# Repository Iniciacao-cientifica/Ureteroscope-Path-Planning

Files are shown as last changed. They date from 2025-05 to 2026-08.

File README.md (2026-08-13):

# Semi-automatic Ureteroscopy Planning VR

Academic prototype that converts a navigable urinary-tract mask into validated routes and an interactive Meta Quest case. The clinical workflow remains human-in-the-loop: anatomy and entry point are reviewed before route generation.

> Research/training prototype only. It is not validated for diagnosis, patient care, intra-operative navigation, or robotic control.

## Current workflow

```text
Reviewed anatomy mask + entry point
                 |
Optional stone mask -> automatic 3D components and targets
                 |
             A* routes
                 |
Safe B-Spline + route validation
                 |
manifest.json + OBJ meshes + routes.json
                 |
Unity/OpenXR -> Meta Quest
```

The original classification project is intentionally not required. A stone segmentation mask can be supplied when a validated model is available; otherwise the operator provides a target.

## Quick start

Install Python dependencies and generate the sample case:

```powershell
python -m pip install -r requirements-vr-export.txt
.\build_vr_case.cmd -MaskDir map -CaseId murillo_sample_case -SpacingMm "2,2,2"
```

This creates `cases/murillo_sample_case/`, validates it, and synchronizes it with `UnityVRPrototype/Assets/StreamingAssets/Cases/`.

With a 3D stone mask in the same geometry:

```powershell
.\build_vr_case.cmd `
  -MaskDir "data\case_001\lumen" `
  -StoneMask "data\case_001\stones.nii.gz" `
  -CaseId "case_001" `
  -Start "253,355,20" `
  -SpacingMm "0.72,0.72,1.0"
```

The stone mask is split into 3D connected components. The pipeline calculates centroid, volume, equivalent diameter, and a route for each retained component. If a centroid is outside the navigable mask, the planning target is snapped to its nearest navigable voxel and both locations remain recorded.

## Build and install on Quest

After installing Android Build Support and configuring the headset:

```powershell
.\build_vr_case.cmd -MaskDir map -CaseId murillo_sample_case -SpacingMm "2,2,2" -BuildApk
```

To build and install on an authorized USB-connected Quest:

```powershell
.\build_vr_case.cmd -MaskDir map -CaseId murillo_sample_case -SpacingMm "2,2,2" -Install
```

The APK is written to `UnityVRPrototype/Builds/UreteroscopyVR.apk`. See [Quest setup and testing](docs/QUEST_TESTING.md).

## Unity interaction

- Grip with one controller: move and rotate the model.
- Grip with both controllers: move and scale the model.
- `X`: anatomy visibility.
- `Y`: route visibility.
- `A`: start/stop route marker.
- `B`: next route/stone.
- Left thumbstick up/down: anatomy opacity.
- Left thumbstick click: reset model.
- Right thumbstick left/right: previous/next case.
- Controller ray + trigger: use the world-space menu.

Editor keyboard fallback: `O`, `P`, `F`, `N`, `C`, `R`, `+`, and `-`.

## Desktop training game

The Unity project also includes a monitor-based academic training mode with an endoscopic camera, minimap, three difficulty levels, wall collisions, score, and anonymous local CSV results. It works with keyboard/mouse or the ESP32-S3 physical probe controller.

Open `Assets/Scenes/UreteroscopyDesktopTraining.unity` or use `Murillo VR > Setup Desktop Training Scene`. Build a Windows executable with `Murillo VR > Build Desktop Training (Windows)`.

See [desktop training](docs/DESKTOP_TRAINING.md) and [physical controller assembly](docs/PHYSICAL_CONTROLLER.md).

## DICOM/NIfTI

Install optional medical I/O dependencies:

```powershell
python -m pip install -r requirements-medical-io.txt
python dicom_to_nifti.py "anonymized_dicom" "case_001_ct.nii.gz"
```

The converter preserves spacing, origin, and direction in a geometry JSON but deliberately copies no patient tags. The input must already be authorized and de-identified.

## Validation

```powershell
python -m unittest discover -s tests -v
python validate_vr_case.py cases\murillo_sample_case
```

Inside Unity use `Murillo VR > Validate Project`. The APK build runs the same validation automatically.

The v2 case interface is documented in [CASE_FORMAT.md](docs/CASE_FORMAT.md). Remaining data and hardware dependencies are documented in [AUTOMATION_STATUS.md](docs/AUTOMATION_STATUS.md).

## Practical Windows note

Unity batch mode can fail when the project is inside OneDrive or a path containing accents. For `-BuildApk`, the build script now stages a temporary copy under an ASCII-only path automatically and copies the APK back afterward. A clean worktree such as `C:\UnityWork\UreteroscopyVR` is still recommended when opening or building the project manually in the Editor.

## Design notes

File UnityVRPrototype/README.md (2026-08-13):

# Ureteroscopy Planning VR — Unity project

Unity 6000.5/OpenXR application for loading versioned ureteroscopy cases from `Assets/StreamingAssets/Cases` on Desktop and Android.

## Prepare

From the repository root:

```powershell
.\build_vr_case.cmd -MaskDir map -CaseId murillo_sample_case -SpacingMm "2,2,2"
```

Open this project, wait for package resolution, and run:

```text
Murillo VR > Setup Sample Scene
Murillo VR > Configure OpenXR Android
Murillo VR > Validate Project
```

The setup creates a real XR Origin hierarchy, tracked head/controllers, controller rays, a world-space menu, the asynchronous case loader, and the build scene.

## Android requirements

Use Unity Hub to add the following modules to Unity `6000.5.0f1`:

- Android Build Support
- Android SDK & NDK Tools
- OpenJDK

The automated build configures IL2CPP, ARM64, Vulkan, minimum API 29, OpenXR for Android, Oculus Touch, and Meta Quest Touch Plus profiles.

## Runtime design

- JSON and OBJ files are loaded with `UnityWebRequest`, including Android `jar:` StreamingAssets paths.
- OBJ is parsed at runtime, so cases are not tied to scene asset GUIDs.
- Route points and meshes are already exported in Unity metres with Y up.
- The camera remains head-tracked while the route marker moves, reducing artificial camera motion.
- One/two-hand grips manipulate the case root.
- Catalog and route changes dispose the previous case objects before loading the next.

## Build

Use the repository command rather than building manually:

```powershell
.\build_vr_case.cmd -MaskDir map -CaseId murillo_sample_case -SpacingMm "2,2,2" -BuildApk
```

The build fails early when the catalog, case files, OpenXR loader, Android module, or OBJ parser is unavailable.

## Desktop training

Open `Assets/Scenes/UreteroscopyDesktopTraining.unity` and press Play. The setup screen selects keyboard/mouse or the USB physical probe, three difficulty levels, anonymous participant code, and 100 mm encoder calibration. Build Windows from `Murillo VR > Build Desktop Training (Windows)`.

## Clinical boundary

Academic/educational prototype only. Not validated for clinical diagnosis, intra-operative navigation, treatment, or patient care.

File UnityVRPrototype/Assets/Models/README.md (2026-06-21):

Import generated anatomy meshes here.

Expected first mesh:

`../exports/murillo_sample_case/urinary_tract_unity.obj`

The repository's `prepare_unity_case.ps1` script copies the sample mesh here automatically.
After Unity imports the OBJ, use `Murillo VR > Setup Sample Scene`; the setup script assigns
the mesh to the `VrCaseLoader` component.

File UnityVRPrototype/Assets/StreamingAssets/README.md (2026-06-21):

Copy the generated `vr_route_unity.json` file into this folder.

Example source after running the Python exporter:

`../exports/murillo_sample_case/vr_route_unity.json`

The repository's `prepare_unity_case.ps1` script copies the sample route here automatically.
After the file exists, use `Murillo VR > Setup Sample Scene` in Unity to create the Quest
sample scene and wire the loader.

The generated `urinary_tract.obj` should be imported into `Assets/Models/` and assigned to
the `Urinary Tract Mesh` field on the `VrCaseLoader` component.

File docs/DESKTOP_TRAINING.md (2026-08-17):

# Treinador desktop com vareta física

Protótipo acadêmico/educacional para navegação em uma máscara anatômica revisada. Não é um dispositivo médico e não deve ser usado em pacientes, procedimentos clínicos, diagnóstico, navegação intraoperatória ou controle de equipamentos.

## O que já funciona

- Visão endoscópica na ponta virtual e minimapa externo.
- Casos, pedras e rotas do pipeline v2 já existente.
- Tutorial com rota interna, intermediário com rota somente no minimapa e avançado sem rota.
- Modo `Treinamento`, confinado à anatomia e ao corredor seguro da rota, e modo `Exploração livre`, sem pontuação ou CSV.
- Controle por teclado/mouse ou ESP32-S3 via USB.
- Colisões nas duas direções, tempo, desvio RMS, eficiência, pontuação e resultado CSV anônimo.
- Seta 3D ciano indicando o próximo trecho da rota e laboratório científico estilizado na exploração.
- Pausa após 500 ms sem pacotes do controle.

## Executar o build pronto no Windows

1. Abra `UnityVRPrototype/Builds/Desktop/UreteroscopyTraining.exe`.
2. Não mova somente o arquivo `.exe`: mantenha-o ao lado da pasta `UreteroscopyTraining_Data`.
3. Na tela inicial escolha `Treinamento`, `Teclado`, dificuldade `Tutorial` e um código anônimo, por exemplo `TESTE-001`.
4. Inicie a sessão e confirme que aparecem a visão interna, o minimapa, a rota, a pedra e as métricas.

No modo teclado:

- `W/S`: avanço e recuo;
- mouse ou setas: inclinação e direção;
- botão esquerdo/direito do mouse: avanço e recuo (alternativa ao `W/S`);
- `Q/E`: rotação axial;
- `Espaço` ou botão central do mouse: botão de ação;
- `C`: calibração/recentralização.

A sensibilidade do mouse pode ser ajustada entre `0,5` e `4,0` na tela inicial e fica salva para as próximas execuções.

No modo `Exploração livre`, a ponta pode atravessar e sair da anatomia. Esse modo não calcula nota, colisões ou métricas e não grava CSV. O laboratório azul-petróleo é um ambiente visual acadêmico estilizado e não representa anatomia real.

Se o Windows SmartScreen bloquear o executável compilado localmente, selecione `Mais informações > Executar assim mesmo`. Não faça isso com executáveis recebidos de origem desconhecida.

## Abrir e testar no Unity

O projeto usa Unity `6000.5.0f1`. No Unity Hub escolha `Add project from disk` e selecione a pasta `UnityVRPrototype`, não a raiz do repositório.

Abra `Assets/Scenes/UreteroscopyDesktopTraining.unity` e pressione Play. A cena já está versionada. Use `Murillo VR > Setup Desktop Training Scene` apenas se ela estiver ausente ou precisar ser reconstruída.

Pare o Play Mode antes de editar a cena. Alterações feitas pelo Inspector enquanto o jogo está rodando normalmente são descartadas ao pressionar Stop.

### Ajustes manuais seguros

Selecione `Desktop Training Controller` na Hierarchy para ajustar:

- `Tip Radius Meters`: raio físico da ponta virtual;
- `Millimeters Per Encoder Tick`: escala de avanço do encoder;
- `Rotation Smoothing`: suavização da orientação;
- tolerâncias de distância, ângulo e permanência no alvo;
- desvio máximo da rota, limite de colisões e duração do flash vermelho;
- sensibilidade do mouse e modo inicial da experiência;
- modo de entrada e porta serial padrão.

Selecione `Training Case Loader` para ajustar:

- cores e transparência da anatomia;
- cores da pedra, rota, início e alvo;
- espessura da rota e tamanho dos marcadores;
- duração da animação que percorre a rota.

O campo de visão da câmera, o material interno e o HUD são configurados por `Assets/Scripts/UreteroscopyTrainingController.cs`. Esses itens exigem alteração de código, recompilação e um novo teste.

Salve a cena com `Ctrl+S`. Para gerar um novo executável use `Murillo VR > Build Desktop Training (Windows)`. O resultado fica em `UnityVRPrototype/Builds/Desktop/UreteroscopyTraining.exe`.

## Usar a vareta física

1. Grave o firmware em `hardware/firmware/ureteroscope_controller` no ESP32-S3.
2. Conecte o ESP32 ao computador por USB e mantenha a vareta imóvel durante os dois segundos de calibração do giroscópio.
3. No jogo escolha `Vareta USB` e deixe a porta como `AUTO`.
4. Se a conexão automática falhar, consulte a porta no Gerenciador de Dispositivos do Windows e informe `COM3`, `COM4` ou a porta encontrada.
5. Use a calibração guiada e desloque exatamente 100 mm para calcular `mm por tick`.
6. Inicie uma sessão curta: o MPU6050 controla a orientação e o encoder mede avanço e recuo.

O jogo pausa depois de 500 ms sem pacotes válidos. Nesse caso confira o cabo USB, a porta COM, o Serial Monitor fechado e a taxa do firmware.

## Problemas comuns

- **O executável não abre:** confirme que a pasta `UreteroscopyTraining_Data` continua ao lado do `.exe`.
- **Tela sem caso ou rota:** abra a Console do Unity, procure o primeiro erro vermelho e confirme que `StreamingAssets/Cases` foi incluído no build.
- **Alteração sumiu:** ela provavelmente foi feita durante o Play Mode; repita com o jogo parado e salve a cena.
- **A vareta não conecta:** feche o Serial Monitor do Arduino, use `AUTO` ou informe a porta COM manualmente.
- **O movimento avança na direção errada:** refaça a calibração de 100 mm e, se necessário, inverta os canais A/B do encoder.
- **A orientação deriva:** recoloque a vareta na posição neutra, mantenha-a imóvel e pressione o botão de calibração ou `C` no simulador.
- **A ponta não atravessa uma abertura no treinamento:** isso é esperado quando a abertura sai do corredor seguro de 15 mm; use `Exploração livre` para inspecionar o exterior.

## Aprendizado recomendado

Para operar e adaptar este protótipo, aprenda nesta ordem:

1. Hierarchy, Scene, Game, Inspector, GameObjects e componentes;
2. materiais, iluminação e câmeras;
3. Play Mode, Console e build para Windows;
4. Arduino IDE, porta serial e gravação no ESP32;
5. barramento I2C, MPU6050 e encoder incremental.

Materiais de referência:

- [Unity Essentials](https://learn.unity.com/pathway/unity-essentials?language=en), curso oficial para Editor, objetos, física, scripts e publicação;
- [abrir um projeto pelo Unity Hub](https://learn.unity.com/tutorial/open-the-unity-essentials-project), tutorial oficial;
- [Unity Creative Core](https://learn.unity.com/pathway/creative-core?language=en), para materiais, luzes, câmeras, VFX e áudio;
- [canal oficial do Unity no YouTube](https://www.youtube.com/@unity), pesquisando por `Unity 6 Editor`, `Lighting`, `Materials` e `Build`;
- [Arduino ESP32: primeiros passos](https://docs.espressif.com/projects/arduino-esp32/en/latest/getting_started.html), documentação oficial;
- [canal oficial da Espressif no YouTube](https://www.youtube.com/@EspressifSystems) e [introdução ao ESP32-S3](https://www.youtube.com/watch?v=AuO-pQbbZCE);
- [canal oficial do Arduino no YouTube](https://www.youtube.com/@Arduino).

## Regras e dados

A sessão termina quando a ponta permanece por 0,5 s a no máximo `máx(raio da pedra + 5 mm, 8 mm)`, aponta para o alvo com erro de até 15 graus e o usuário aciona o gatilho. Impactos contra faces internas ou externas são bloqueados tanto no avanço quanto no recuo. O corredor de segurança começa em 15 mm ao redor da rota e impede fugas por pequenas aberturas da malha. Manter o movimento pressionado durante um contato conta uma colisão; afastar e colidir novamente inicia outro episódio. A quinta colisão encerra a tentativa como `DNF`.

A nota combina segurança (40), precisão (30), eficiência (20) e tempo (10). O botão `DESISTIR` pede confirmação; sessões confirmadas são registradas como `DNF` e não recebem nota. O CSV fica em `%USERPROFILE%/AppData/LocalLow/<Company>/<Product>/Sessions/ureteroscopy_sessions.csv` e contém apenas código escolhido pelo pesquisador, caso, rota, dificuldade e métricas. Não digite nome, CPF, prontuário ou outro identificador pessoal.

## Limitação anatômica

O início é o ponto de entrada humano-revisado da máscara disponível. A cena não afirma reproduzir todo o percurso externo, uretra, bexiga, ureter e rim. Uma simulação contínua dessas estruturas depende de dados segmentados e validados que ainda não estão no repositório.

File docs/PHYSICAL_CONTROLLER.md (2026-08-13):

# Controle físico ESP32-S3 + MPU6050 + encoder

## Lista de materiais

| Quantidade | Componente | Observação |
|---:|---|---|
| 1 | ESP32-S3 DevKitC-1 ou compatível | USB CDC, alimentação pelo computador |
| 1 | GY-521/MPU6050 | IMU econômica 6DoF, endereço I2C `0x68` |
| 1 | KY-040 ou encoder EC11 de 20 pulsos | Medição por quadratura |
| 1 | Roda impressa + O-ring 20 x 2 mm | Mantém contato com a vareta |
| 2 | Botões momentâneos normalmente abertos | Ação e calibração |
| 1 | LED + resistor de 220 ohms | Opcional se a placa não tiver LED utilizável |
| 1 | Vareta lisa de 10 mm | Apenas simulador de mesa; nunca inserir em pessoa |
| 1 | Mola pequena de compressão | Pressão da roda sobre a vareta |
| 3 | Parafusos M3, porcas e arruelas | Pivô e ajuste do encoder |
| 4 | Parafusos M4 | Fixação da base à mesa |
| 1 | Cabo USB de dados | Não usar cabo somente de carga |

O valor inicial de `0,785 mm/tick` considera roda efetiva de 20 mm e encoder de 20 pulsos contado nas quatro transições. Sempre execute a calibração real de 100 mm porque diâmetro, O-ring e encoder variam.

## Ligações

| ESP32-S3 | Componente |
|---|---|
| 3V3 | VCC do GY-521 |
| GND | GND comum, encoder e botões |
| GPIO 8 | SDA do GY-521 |
| GPIO 9 | SCL do GY-521 |
| GPIO 4 | Canal A/CLK do encoder |
| GPIO 5 | Canal B/DT do encoder |
| GPIO 6 | Botão de ação para GND |
| GPIO 7 | Botão de calibração para GND |

Não alimente o GY-521 com 5 V quando os resistores de pull-up I2C da placa não forem confirmados para 3,3 V. O firmware usa `INPUT_PULLUP` para encoder e botões.

## Firmware

O código está em `hardware/firmware/ureteroscope_controller` e pode ser aberto diretamente na Arduino IDE. Instale pelo Library Manager:

- `Adafruit MPU6050` e dependências;
- `Madgwick` da Arduino Libraries;
- pacote de placas `esp32` da Espressif.

Selecione uma placa ESP32-S3, habilite USB CDC ao iniciar, compile e grave. O arquivo `platformio.ini` permite a alternativa PlatformIO. A inicialização exige dois segundos com o controle imóvel para estimar o viés do giroscópio.

O firmware transmite JSON delimitado por nova linha a 115200 baud e 50 Hz:

```json
{"v":1,"seq":1,"ms":100,"q":[1,0,0,0],"ticks":20,"buttons":0,"imu_ok":true,"fw":"mpu6050-encoder-v1.0.0"}
```

O quaternion usa ordem `[w,x,y,z]`. `buttons` usa bit 0 para ação e bit 1 para calibração. O Unity rejeita versões, quaternions ou mensagens inválidas.

## Impressão e montagem

O modelo paramétrico está em `hardware/cad/ureteroscope_controller.scad`. Parâmetros principais: `rod_diameter`, `print_tolerance` e `encoder_shaft_diameter`. Exporte os seis STL com:

```powershell
.\hardware\cad\export_stl.ps1
```

Configuração inicial: PETG ou PLA, camada de 0,2 mm, quatro perímetros e 25% de preenchimento. Rebarbe a bucha sem aumentar folga excessivamente. Coloque um O-ring na roda, monte o braço com M3 e use a mola/parafuso para obter contato sem travar a vareta. Fixe a IMU rigidamente no cabo, com os eixos sempre na mesma orientação.

## Calibração e aceite

1. Prenda a base à mesa e confirme que a vareta desliza sem folga lateral perceptível.
2. No jogo selecione `Vareta USB`, deixe a porta em `AUTO` ou informe `COM3`, por exemplo.
3. Clique `Calibrar encoder 100 mm`, marque o zero, avance exatamente 100 mm e conclua. A escala fica salva no computador.
4. Inicie uma sessão, mantenha a vareta imóvel e calibre a orientação. Repita a recentralização entre tentativas.
5. Faça cinco ciclos de 200 mm. Cada leitura deve ter erro absoluto máximo de 5 mm e não pode perder contato.
6. Verifique resposta visual abaixo de 100 ms e deriva parada menor que 10 graus em três minutos.

O MPU6050 não possui magnetômetro, acumula deriva de rumo e foi descontinuado pelo fabricante. Módulos GY-521 podem usar componentes clones. Esta escolha é adequada somente à prova de conceito; a interface do Unity permite uma futura troca por BNO085 sem mudar as regras do jogo.

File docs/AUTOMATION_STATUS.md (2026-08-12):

# Automation status and external blockers

## Implemented

- Anatomy mask loading from PNG stack, NPY, or NIfTI.
- Optional DICOM-to-NIfTI conversion preserving geometry.
- Optional 3D stone-mask component extraction.
- Automatic stone centroid, volume, diameter, and planning-target generation.
- One validated A*/B-Spline route per detected stone.
- Physical units, extrapolation checks, and versioned case validation.
- Unity case catalog, Android-safe asynchronous loading, runtime OBJ parsing, multiple routes/cases, VR manipulation, menu, and build/install command.

## Requires data or a person

- The anatomy mask and entry point remain human-reviewed.
- The stone-segmentation repository contains a TensorFlow checkpoint (`my_checkpoint`, about 16.8 MB) and several notebook-defined architectures, but no notebook or script references that checkpoint and no metadata identifies its architecture, input normalization, training split, or decision threshold. Loading it against a guessed network would be technically possible but scientifically invalid. A reproducible inference command therefore requires confirmation from the original author or retraining/exporting a named model with a patient-level split.
- Automatic collecting-system/ureter segmentation cannot be trained or validated from the current repositories because matching labeled 3D volumes are absent.
- Real DICOM geometry can only be validated after authorized anonymized examinations and corresponding masks are provided.
- Clinical correctness requires expert review and, for formal participant research, guidance about ethics approval.
- Quest comfort and performance require a physical headset test.

## Recommended IC boundary

The defensible primary result is a semi-automatic, human-in-the-loop planning and training prototype. Full anatomical segmentation, intra-operative tracking, clinical decision support, and robotics remain future work.

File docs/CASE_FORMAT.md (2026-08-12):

# VR case format v2

Each case is self-contained:

```text
case_001/
├── manifest.json
├── anatomy.obj
├── stones.obj       # optional
├── routes.json
├── route.csv
└── thumbnail.png    # optional
```

`catalog.json` sits one directory above the cases and references each `manifest.json`.

## Coordinate contract

- Source mask array order: `z,y,x`.
- User-facing planning coordinates: voxel `x,y,z`.
- Spacing: millimetres in `x,y,z`.
- Exported OBJ vertices and route points: Unity `x,y-up,z` in metres.
- Conversion: apply the DICOM/NIfTI direction matrix to `index * spacing`, then map relative patient `(x,z,y)` to Unity metres.

Unity must not apply another voxel scale to schema-v2 cases.

## Required manifest fields

- `schema_version`: `2`.
- `case_id`: anonymous letters/numbers/underscore/hyphen identifier.
- `display_name`: non-identifying label.
- `volume_shape_zyx` and `spacing_mm_xyz`.
- `spacing_assumed`: warns when real spacing was unavailable.
- `files.anatomy` and `files.routes`.
- `stones` and `route_count`.
- academic `clinical_notice`.

Absolute source paths and patient identifiers are deliberately excluded.

## Routes

`routes.json` contains an array. Each route records:

- route and stone identifiers;
- start, requested target, and navigable planning target;
- original, smoothed, and dense visual paths;
- physical length and final error in millimetres;
- wall-risk and outside-mask checks;
- curvature, torsion, and processing time.

The dense route is only for rendering. Metrics remain based on the validated planning route.

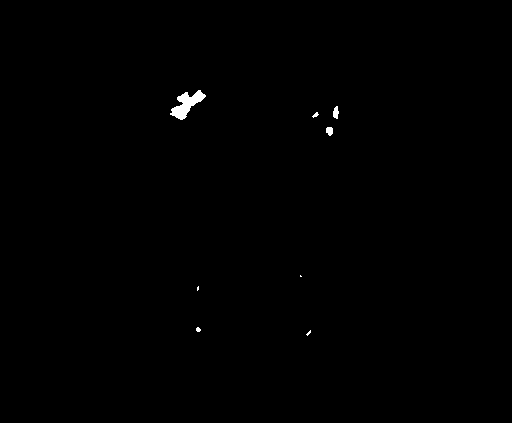
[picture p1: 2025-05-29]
map/mask_278.png

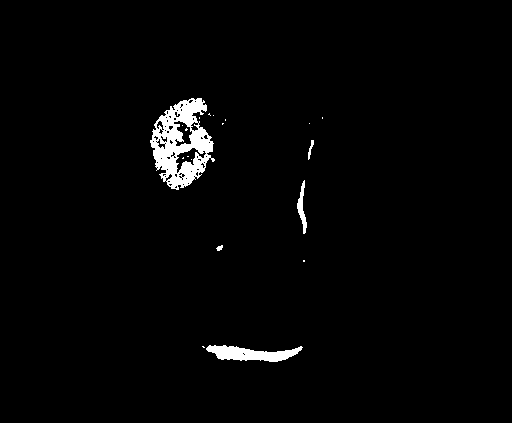
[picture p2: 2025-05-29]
map/mask_238.png

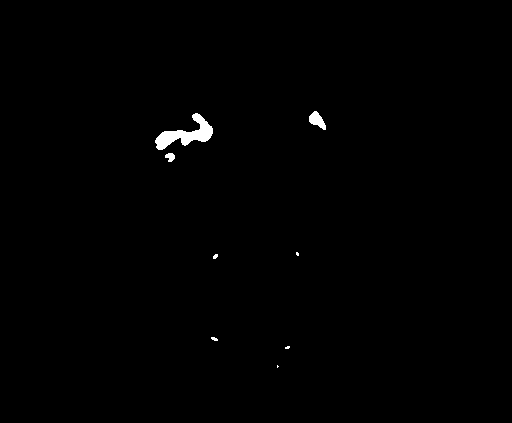
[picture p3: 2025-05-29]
map/mask_259.png

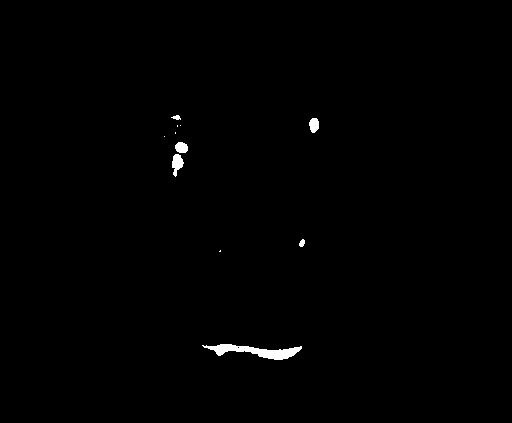
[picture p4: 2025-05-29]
map/mask_246.png

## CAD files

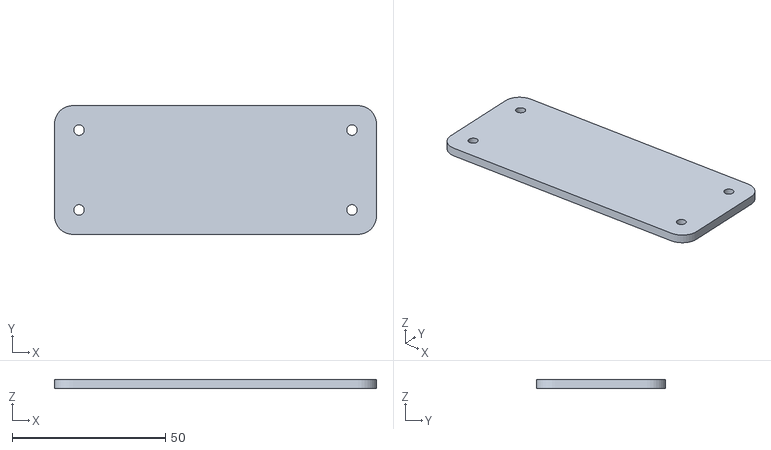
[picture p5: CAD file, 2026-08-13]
hardware/cad/stl/handle_lid.stl
105.0 x 42.0 x 3.00

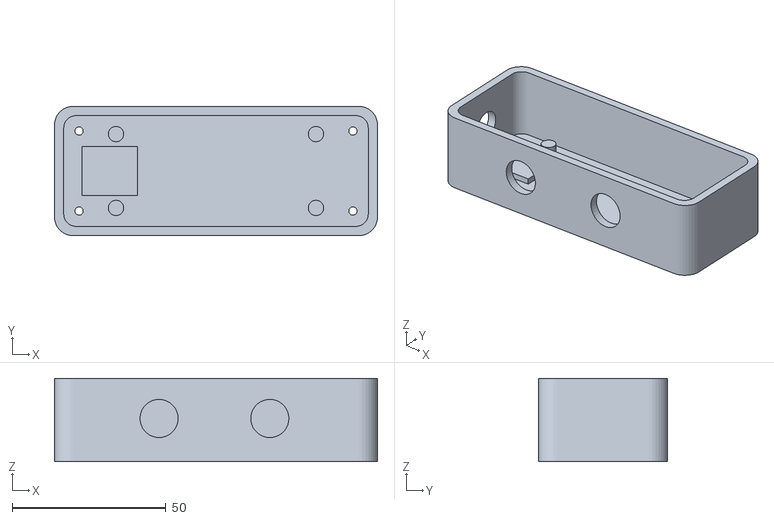
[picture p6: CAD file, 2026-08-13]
hardware/cad/stl/handle_body.stl
105.0 x 42.0 x 27.0

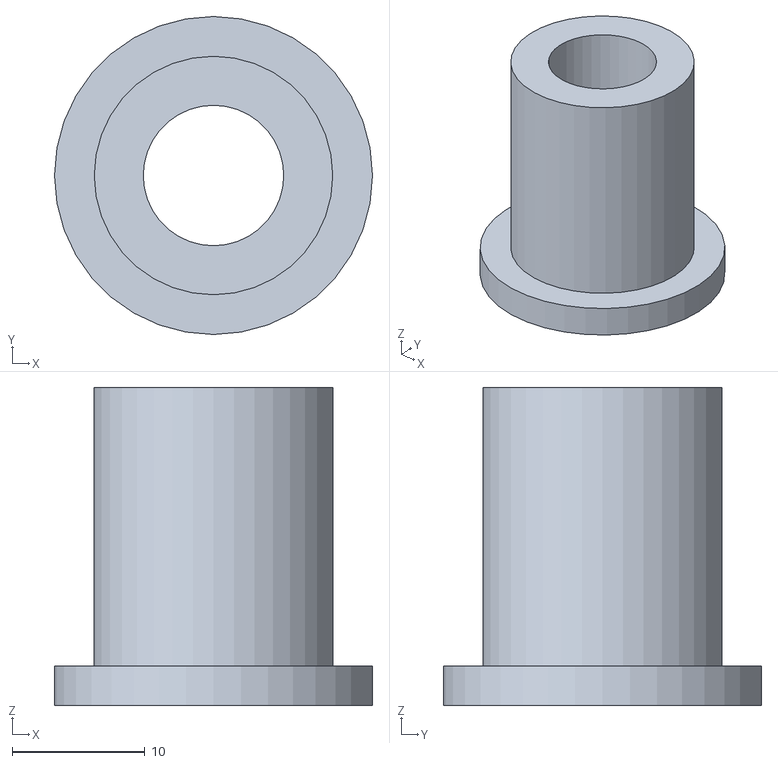
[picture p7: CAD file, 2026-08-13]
hardware/cad/stl/guide_bushing.stl
24.0 x 24.0 x 24.0

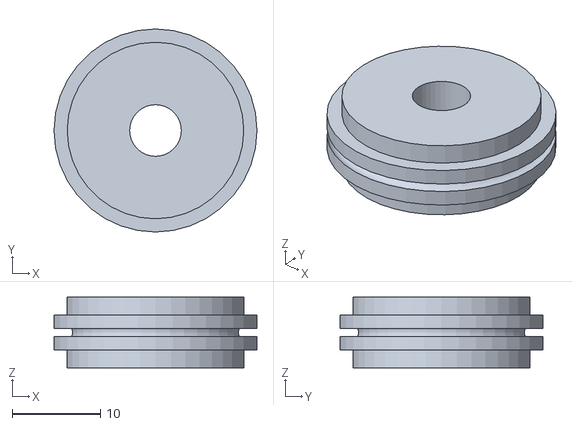
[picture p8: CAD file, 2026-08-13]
hardware/cad/stl/encoder_wheel.stl
23.0 x 23.0 x 8.00

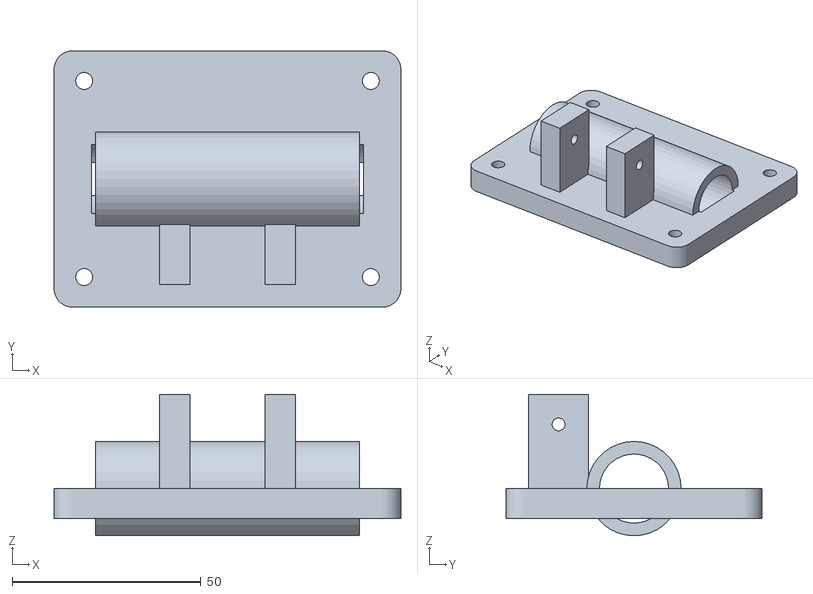
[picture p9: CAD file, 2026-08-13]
hardware/cad/stl/guide_base.stl
92.0 x 68.0 x 37.5

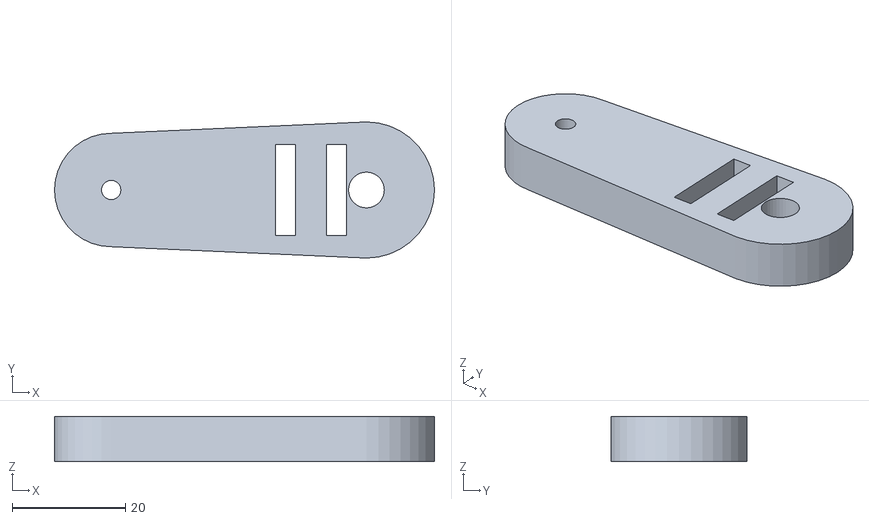
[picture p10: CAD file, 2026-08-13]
hardware/cad/stl/encoder_arm.stl
67.0 x 24.0 x 8.00

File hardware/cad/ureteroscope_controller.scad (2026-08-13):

// Parametric desktop ureteroscope controller fixture.
// Units: millimetres. Print in PETG or PLA, 0.2 mm layers, 4 perimeters.
// Select one part by index with -D export_part=3 (see dispatch table at the end).

$fn = 36;
export_part = 0;
rod_diameter = 10;
print_tolerance = 0.30;
encoder_shaft_diameter = 6;
m3_clearance = 3.4;

module rounded_box(size, radius) {
  hull() {
    for (x = [radius, size[0] - radius])
      for (y = [radius, size[1] - radius])
        translate([x, y, 0]) cylinder(h = size[2], r = radius);
  }
}

module handle_body() {
  difference() {
    rounded_box([105, 42, 27], 6);
    translate([3, 3, 3]) rounded_box([99, 36, 25], 4);
    // USB cable, two 12 mm pushbuttons and four M3 lid screws.
    translate([-1, 21, 13.5]) rotate([0, 90, 0]) cylinder(h = 7, d = 10);
    for (x = [34, 70]) translate([x, -1, 14]) rotate([-90, 0, 0]) cylinder(h = 6, d = 12.4);
    for (x = [8, 97]) for (y = [8, 34]) translate([x, y, -1]) cylinder(h = 8, d = 2.7);
  }
  // ESP32-S3 board supports: nominal board 69 x 28 mm.
  for (x = [20, 85]) for (y = [9, 33]) translate([x, y, 3]) cylinder(h = 4, d = 5);
  // IMU shelf kept near the probe axis.
  translate([9, 13, 3]) cube([18, 16, 2]);
}

module handle_lid() {
  difference() {
    rounded_box([105, 42, 3], 6);
    for (x = [8, 97]) for (y = [8, 34]) translate([x, y, -1]) cylinder(h = 5, d = m3_clearance);
  }
}

module guide_base() {
  difference() {
    union() {
      rounded_box([92, 68, 8], 5);
      translate([11, 34, 8]) rotate([0, 90, 0]) cylinder(h = 70, d = 25);
      // Encoder pivot cheeks.
      translate([28, 6, 8]) cube([8, 16, 25]);
      translate([56, 6, 8]) cube([8, 16, 25]);
    }
    // Replaceable guide bushing bore.
    translate([10, 34, 8]) rotate([0, 90, 0]) cylinder(h = 72, d = 18.3);
    // M3 pivot and spring preload screw.
    translate([26, 14, 25]) rotate([0, 90, 0]) cylinder(h = 40, d = m3_clearance);
    translate([46, -1, 15]) rotate([-90, 0, 0]) cylinder(h = 18, d = m3_clearance);
    // Four table fixing holes.
    for (x = [8, 84]) for (y = [8, 60]) translate([x, y, -1]) cylinder(h = 11, d = 4.5);
  }
}

module guide_bushing() {
  difference() {
    union() {
      cylinder(h = 24, d = 18);
      cylinder(h = 3, d = 24);
    }
    translate([0, 0, -1]) cylinder(h = 27, d = rod_diameter + 2 * print_tolerance);
  }
}

module encoder_arm() {
  difference() {
    hull() {
      translate([0, 0, 0]) cylinder(h = 8, d = 20);
      translate([45, 0, 0]) cylinder(h = 8, d = 24);
    }
    translate([0, 0, -1]) cylinder(h = 10, d = m3_clearance);
    translate([45, 0, -1]) cylinder(h = 10, d = encoder_shaft_diameter + print_tolerance);
    // Two slots accept the KY-040/EC11 board or M3 zip-tie anchors.
    for (x = [29, 38]) translate([x, -8, -1]) cube([3.5, 16, 10]);
  }
}

module encoder_wheel() {
  difference() {
    union() {
      cylinder(h = 8, d = 20);
      translate([0, 0, 2]) cylinder(h = 4, d = 23);
    }
    translate([0, 0, -1]) cylinder(h = 10, d = encoder_shaft_diameter - 0.15);
    // Groove for a 20 x 2 mm O-ring or rubber band.
    rotate_extrude() translate([10.5, 4, 0]) circle(d = 2.2, $fn = 24);
  }
}

module assembly() {
  color("SlateGray") guide_base();
  color("LightSkyBlue") translate([10, 34, 20.5]) rotate([0, 90, 0]) guide_bushing();
  color("Orange") translate([46, 14, 26]) rotate([90, 0, 0]) encoder_arm();
  color("Black") translate([46, 34 + rod_diameter / 2 + 10, 21]) rotate([90, 0, 0]) encoder_wheel();
  color("Silver") translate([-25, 34, 20.5]) rotate([0, 90, 0]) cylinder(h = 145, d = rod_diameter);
}

if (export_part == 1) handle_body();
else if (export_part == 2) handle_lid();
else if (export_part == 3) guide_base();
else if (export_part == 4) guide_bushing();
else if (export_part == 5) encoder_arm();
else if (export_part == 6) encoder_wheel();
else assembly();

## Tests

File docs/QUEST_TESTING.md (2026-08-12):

# Meta Quest setup and testing

## Phone and Meta account

1. Install/update **Meta Horizon** on the phone.
2. Sign in with the headset owner's Meta account and pair the Quest.
3. Join or create a developer team in the Meta Horizon Developer Dashboard.
4. Verify the developer account with phone number or accepted payment method.
5. In Meta Horizon open the headset icon, select the paired Quest, open **Headset Settings > Developer Mode**, and enable it.

The phone itself does not need Android developer options and is not connected to Unity.

## Headset and computer

1. Restart the Quest.
2. Connect it using a USB-C data cable.
3. In the headset open Quick Settings > Settings > Developer and enable MTP notifications.
4. Accept **Allow USB debugging** and **Always allow from this computer**.
5. Install the official Oculus ADB driver on Windows.
6. Confirm the device using Unity's ADB:

```powershell
& "C:\Program Files\Unity\Hub\Editor\6000.5.0f1\Editor\Data\PlaybackEngines\AndroidPlayer\SDK\platform-tools\adb.exe" devices
```

Expected status: `device`. `unauthorized` means the confirmation inside the headset is still pending.

## Test cycle

1. Build/install with `build_vr_case.cmd ... -Install`.
2. Verify launch, head tracking, both controllers, rays, menu, model grips, route animation, cases, and routes.
3. Run continuously for 15 minutes.
4. Record FPS, loading time, visual alignment, discomfort, and the exact control used before any failure.
5. Collect logs:

```powershell
$Adb = "C:\Program Files\Unity\Hub\Editor\6000.5.0f1\Editor\Data\PlaybackEngines\AndroidPlayer\SDK\platform-tools\adb.exe"
& $Adb logcat -s Unity
```

## Acceptance checklist

- No black screen or OpenXR initialization error.
- Anatomy, stones, and route remain aligned.
- One-hand move/rotate and two-hand scale work.
- Trigger activates world-menu buttons.
- Route animation can stop immediately.
- Case and route switching do not duplicate objects.
- No crash or severe discomfort in 15 minutes.
- Target performance is stable near the configured 72 Hz refresh rate.

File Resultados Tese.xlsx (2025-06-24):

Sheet: Savgol_50
technique | total_time | window_ratio | order | fitness | extrapolations | mse | curvature_mean | curvature_max | torsao_mean | torsao_max | risk_points | acuracia_final | normalized_extrapolations | normalized_risk_points | normalized_torsao_max
Savitzky-Golay | 12.468 | 0.15 | 7 | 0.468441 | 0 | 0.157598 | 0.03926 | 0.183748 | 0.020511 | 2.774089 | 0 | 0.046041 | 0 | 0 | 0.190744
Savitzky-Golay | 12.506999 | 0.05 | 2 | 0.495512 | 0 | 0.089794 | 0.053077 | 0.159113 | 0.077126 | 1.289018 | 0 | 0.120452 | 0 | 0 | 0.149034
Savitzky-Golay | 12.553002 | 0.05 | 3 | 0.517156 | 0 | 0.087756 | 0.054912 | 0.159113 | 0.088218 | 2.635457 | 0 | 0.049089 | 0 | 0 | 0.186501
Savitzky-Golay | 12.429038 | 0.15 | 9 | 0.526885 | 0 | 0.116951 | 0.049862 | 0.277029 | 0.039647 | 1.12746 | 0 | 0.009172 | 0 | 0 | 0.144983
Savitzky-Golay | 12.357011 | 0.1 | 7 | 0.61285 | 0 | 0.088743 | 0.061724 | 0.294521 | 0.098065 | 1.11192 | 0 | 0.012668 | 0 | 0 | 0.144598
Savitzky-Golay | 12.365994 | 0.1 | 9 | 1.087041 | 0 | 0.048487 | 0.116456 | 0.548165 | 0.184224 | 4.046402 | 0 | 0.00054 | 0 | 0 | 0.23313
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

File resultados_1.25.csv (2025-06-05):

technique | timestamp | total_time | window_ratio | order | smooth_factor | iterations | lambda_factor | fitness | extrapolations | mse | curvature_mean | curvature_max | torsao_mean | torsao_max | risk_points | acuracia_final
Savitzky-Golay | 2025-06-05T16:08:15.167581 | 12,270005 | 0,050000 | 2 |  |  |  | 4,195052 | 0 | 0,144709 | 0,042681 | 0,132878 | 0,052891 | 6,534921 | 0 | 1,178197
Savitzky-Golay | 2025-06-05T16:08:27.503615 | 12,334038 | 0,050000 | 3 |  |  |  | 4,102680 | 0 | 0,142419 | 0,044681 | 0,134683 | 0,049890 | 6,530700 | 0 | 0,998527
Savitzky-Golay | 2025-06-05T16:08:39.766575 | 12,261952 | 0,050000 | 5 |  |  |  | 15,167187 | 0 | 0,085776 | 0,111846 | 0,503134 | 0,151509 | 27,271652 | 0 | 0,985878
Savitzky-Golay | 2025-06-05T16:08:51.929575 | 12,163000 | 0,050000 | 7 |  |  |  | 47972011454,608276 | 0 | 0,000000 | 0,724818 | 1,846315 | 23986005723,947281 | 5,835520 | 0 | 1,000000
Savitzky-Golay | 2025-06-05T16:09:04.182575 | 12,253000 | 0,050000 | 9 |  |  |  | 47972011454,608276 | 0 | 0,000000 | 0,724818 | 1,846315 | 23986005723,947281 | 5,835520 | 0 | 1,000000
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

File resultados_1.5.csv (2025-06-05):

technique | timestamp | total_time | window_ratio | order | smooth_factor | iterations | lambda_factor | fitness | extrapolations | mse | curvature_mean | curvature_max | torsao_mean | torsao_max | risk_points | acuracia_final
Savitzky-Golay | 2025-06-05T15:52:21.587080 | 13,088001 | 0,050000 | 2 |  |  |  | 6,512116 | 1 | 0,162669 | 0,037164 | 0,137449 | 0,000430 | 1,320001 | 0 | 1,246424
Savitzky-Golay | 2025-06-05T15:52:34.058079 | 12,469999 | 0,050000 | 3 |  |  |  | 6,313266 | 1 | 0,158904 | 0,039455 | 0,138891 | 0,018238 | 1,099603 | 0 | 0,986595
Savitzky-Golay | 2025-06-05T15:52:46.437090 | 12,378011 | 0,050000 | 5 |  |  |  | 4,098332 | 0 | 0,085383 | 0,095658 | 0,502766 | 0,029377 | 5,688144 | 0 | 0,985773
Savitzky-Golay | 2025-06-05T15:52:58.771089 | 12,334000 | 0,050000 | 7 |  |  |  | 1104926951848,025391 | 0 | 0,000000 | 0,507879 | 1,791338 | 16615442884,946121 | 2143392132149,652100 | 0 | 1,000000
Savitzky-Golay | 2025-06-05T15:53:11.342238 | 12,571148 | 0,050000 | 9 |  |  |  | 1104926951848,025391 | 0 | 0,000000 | 0,507879 | 1,791338 | 16615442884,946121 | 2143392132149,652100 | 0 | 1,000000
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

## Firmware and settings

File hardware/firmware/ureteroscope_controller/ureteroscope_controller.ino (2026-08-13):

#include <Adafruit_MPU6050.h>
#include <Adafruit_Sensor.h>
#include <MadgwickAHRS.h>
#include <Wire.h>

// ESP32-S3 DevKit defaults. Change only if the selected board routes I2C elsewhere.
constexpr uint8_t PIN_SDA = 8;
constexpr uint8_t PIN_SCL = 9;
constexpr uint8_t PIN_ENCODER_A = 4;
constexpr uint8_t PIN_ENCODER_B = 5;
constexpr uint8_t PIN_ACTION = 6;
constexpr uint8_t PIN_CALIBRATE = 7;
#ifdef LED_BUILTIN
constexpr uint8_t PIN_STATUS_LED = LED_BUILTIN;
#else
constexpr uint8_t PIN_STATUS_LED = 48;
#endif

constexpr float SAMPLE_HZ = 100.0f;
constexpr uint32_t SAMPLE_PERIOD_US = 1000000UL / static_cast<uint32_t>(SAMPLE_HZ);
constexpr uint32_t SEND_PERIOD_MS = 20;
constexpr uint32_t GYRO_CALIBRATION_MS = 2000;
constexpr char FIRMWARE_VERSION[] = "mpu6050-encoder-v1.0.0";

Adafruit_MPU6050 mpu;
Madgwick filter;
volatile int32_t encoderTicks = 0;
volatile uint8_t previousEncoderState = 0;
float gyroBiasX = 0.0f;
float gyroBiasY = 0.0f;
float gyroBiasZ = 0.0f;
bool imuOk = false;
uint32_t sequenceNumber = 0;
uint32_t lastSampleUs = 0;
uint32_t lastSendMs = 0;
bool previousCalibrationButton = false;

void IRAM_ATTR updateEncoder() {
  const uint8_t current = (digitalRead(PIN_ENCODER_A) << 1) | digitalRead(PIN_ENCODER_B);
  // Quadrature lookup table; rejects impossible two-bit jumps caused by bounce.
  static constexpr int8_t transitions[16] = {
    0, -1, 1, 0,
    1, 0, 0, -1,
    -1, 0, 0, 1,
    0, 1, -1, 0
  };
  encoderTicks += transitions[(previousEncoderState << 2) | current];
  previousEncoderState = current;
}

void setStatusLed(bool on) {
  digitalWrite(PIN_STATUS_LED, on ? HIGH : LOW);
}

void calibrateGyroscope() {
  if (!imuOk) return;
  setStatusLed(true);
  double sumX = 0.0;
  double sumY = 0.0;
  double sumZ = 0.0;
  uint32_t count = 0;
  const uint32_t startedAt = millis();
  while (millis() - startedAt < GYRO_CALIBRATION_MS) {
    sensors_event_t acceleration;
    sensors_event_t gyro;
    sensors_event_t temperature;
    mpu.getEvent(&acceleration, &gyro, &temperature);
    sumX += gyro.gyro.x;
    sumY += gyro.gyro.y;
    sumZ += gyro.gyro.z;
    count++;
    delay(4);
  }
  if (count > 0) {
    gyroBiasX = static_cast<float>(sumX / count);
    gyroBiasY = static_cast<float>(sumY / count);
    gyroBiasZ = static_cast<float>(sumZ / count);
  }
  filter = Madgwick();
  filter.begin(SAMPLE_HZ);
  lastSampleUs = micros();
  setStatusLed(false);
}

void eulerDegreesToQuaternion(float rollDegrees, float pitchDegrees, float yawDegrees,
                              float &w, float &x, float &y, float &z) {
  const float roll = rollDegrees * DEG_TO_RAD * 0.5f;
  const float pitch = pitchDegrees * DEG_TO_RAD * 0.5f;
  const float yaw = yawDegrees * DEG_TO_RAD * 0.5f;
  const float cr = cosf(roll);
  const float sr = sinf(roll);
  const float cp = cosf(pitch);
  const float sp = sinf(pitch);
  const float cy = cosf(yaw);
  const float sy = sinf(yaw);
  w = cr * cp * cy + sr * sp * sy;
  x = sr * cp * cy - cr * sp * sy;
  y = cr * sp * cy + sr * cp * sy;
  z = cr * cp * sy - sr * sp * cy;
}

void sendPacket() {
  float w;
  float x;
  float y;
  float z;
  eulerDegreesToQuaternion(filter.getRoll(), filter.getPitch(), filter.getYaw(), w, x, y, z);
  const bool actionPressed = digitalRead(PIN_ACTION) == LOW;
  const bool calibratePressed = digitalRead(PIN_CALIBRATE) == LOW;
  const uint8_t buttons = (actionPressed ? 1 : 0) | (calibratePressed ? 2 : 0);
  int32_t stableTicks;
  noInterrupts();
  stableTicks = encoderTicks;
  interrupts();

  Serial.printf(
    "{\"v\":1,\"seq\":%lu,\"ms\":%lu,\"q\":[%.6f,%.6f,%.6f,%.6f],"
    "\"ticks\":%ld,\"buttons\":%u,\"imu_ok\":%s,\"fw\":\"%s\"}\n",
    static_cast<unsigned long>(sequenceNumber++),
    static_cast<unsigned long>(millis()),
    w, x, y, z,
    static_cast<long>(stableTicks),
    buttons,
    imuOk ? "true" : "false",
    FIRMWARE_VERSION
  );
}

void setup() {
  pinMode(PIN_ENCODER_A, INPUT_PULLUP);
  pinMode(PIN_ENCODER_B, INPUT_PULLUP);
  pinMode(PIN_ACTION, INPUT_PULLUP);
  pinMode(PIN_CALIBRATE, INPUT_PULLUP);
  pinMode(PIN_STATUS_LED, OUTPUT);
  previousEncoderState = (digitalRead(PIN_ENCODER_A) << 1) | digitalRead(PIN_ENCODER_B);
  attachInterrupt(digitalPinToInterrupt(PIN_ENCODER_A), updateEncoder, CHANGE);
  attachInterrupt(digitalPinToInterrupt(PIN_ENCODER_B), updateEncoder, CHANGE);

  Serial.begin(115200);
  Wire.begin(PIN_SDA, PIN_SCL);
  imuOk = mpu.begin(0x68, &Wire);
  if (imuOk) {
    mpu.setAccelerometerRange(MPU6050_RANGE_4_G);
    mpu.setGyroRange(MPU6050_RANGE_500_DEG);
    mpu.setFilterBandwidth(MPU6050_BAND_21_HZ);
    filter.begin(SAMPLE_HZ);
    calibrateGyroscope();
  } else {
    setStatusLed(true);
  }
}

void loop() {
  const uint32_t nowUs = micros();
  if (imuOk && nowUs - lastSampleUs >= SAMPLE_PERIOD_US) {
    lastSampleUs += SAMPLE_PERIOD_US;
    sensors_event_t acceleration;
    sensors_event_t gyro;
    sensors_event_t temperature;
    mpu.getEvent(&acceleration, &gyro, &temperature);
    filter.updateIMU(
      (gyro.gyro.x - gyroBiasX) * RAD_TO_DEG,
      (gyro.gyro.y - gyroBiasY) * RAD_TO_DEG,
      (gyro.gyro.z - gyroBiasZ) * RAD_TO_DEG,
      acceleration.acceleration.x,
      acceleration.acceleration.y,
      acceleration.acceleration.z
    );
  }

  const bool calibrationButton = digitalRead(PIN_CALIBRATE) == LOW;
  if (calibrationButton && !previousCalibrationButton) calibrateGyroscope();
  previousCalibrationButton = calibrationButton;

  const uint32_t nowMs = millis();
  if (nowMs - lastSendMs >= SEND_PERIOD_MS) {
    lastSendMs += SEND_PERIOD_MS;
    sendPacket();
  }
}

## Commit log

2025-06-04 Grid search added
    Added Grid Search to optmize all curves
    [resultados_completos.csv]
2025-06-05 Grid Search results generated
    Generated results using grid search for all methods
    [resultados_1.25.csv, resultados_1.5.csv, resultados_2.csv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]
2025-06-24 Final results generated
    Final results generated for Savitzky-Golay, B-Spline and Laplacian filter using 100%, 75% and 50% resolution of points.
    [Resultados Tese.xlsx, resultados_1.25.csv, resultados_1.5.csv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]
2026-06-18 feat: adiciona protótipo VR para planejamento de ureteroscopia
2026-06-21 feat: prepara prototipo VR para Meta Quest
2026-08-12 Implementa planejamento semiautomático de ureteroscopia em VR
    Implementado:
    1. Cria o formato versionado de casos com unidades físicas, orientação e validação.
    2. Automatiza cálculos 3D, métricas, rotas e exportação de modelos para o Unity.
    3. Adiciona catálogo de casos, carregamento Android assíncrono e parser OBJ no Unity.
    4. Implementa XR Origin, controles, raios, menu VR, manipulação e animação da rota.
    5. Automatiza configuração OpenXR, build do APK, instalação via ADB e importação DICOM/NIfTI.
    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
2026-08-13 feat: adiciona treinamento desktop de ureteroscopia
2026-08-13 feat: adiciona controle fisico e estrutura imprimivel
    [encoder_arm.stl, encoder_wheel.stl, guide_base.stl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]
2026-08-17 fix: preserva camera e controles do treinamento
2026-08-17 feat: adiciona modos de treinamento e exploracao
2026-08-17 fix: inicia controles de teclado automaticamente
